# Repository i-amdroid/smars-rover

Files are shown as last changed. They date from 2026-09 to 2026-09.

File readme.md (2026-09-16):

SMARS ROVER
===========

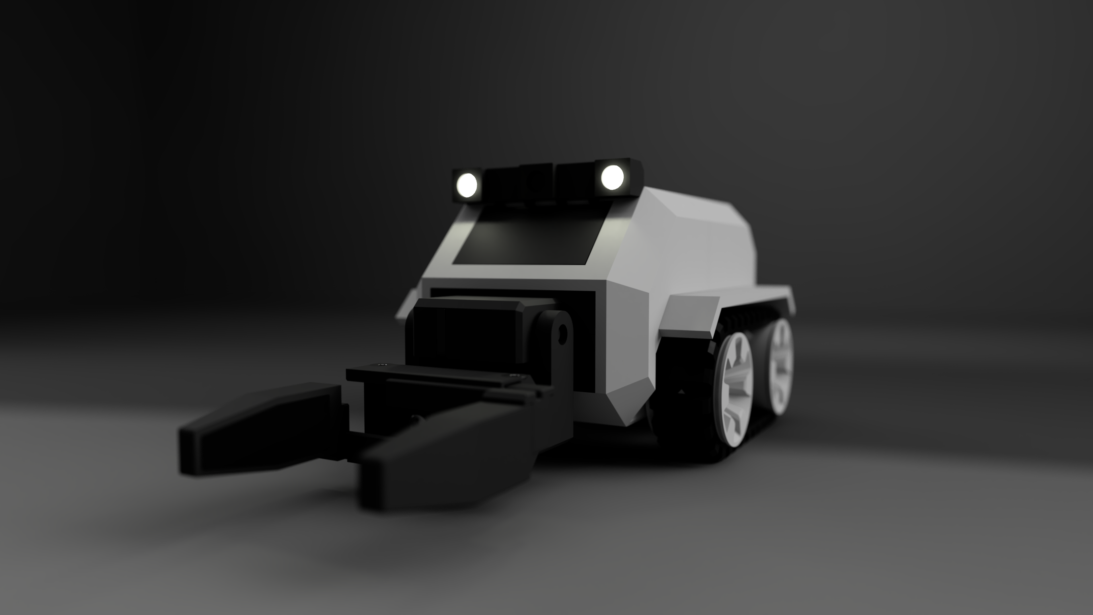
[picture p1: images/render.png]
SMARS ROVER


About the project
-----------------

SMARS ROVER is a modular robotic rover with a finger gripper, controlled remotely over a video stream and powered by an ESP32.
It is built on top of SMARS, an extendable modular robot with plenty of add-ons and a large community behind it.
The design was inspired by Toyota's JAXA lunar rover, the Mars rover from The Martian, and the original SMARS project.

Project features
----------------

* A complete, working project — free and open source
* Fully compatible with the SMARS robot project and most of its add-ons
* Rover body v3, carefully designed based on years of experience
* Improved chassis with support for a Li-ion battery and charging
* Flexible tracks and redesigned wheels
* Finger gripper that moves in two dimensions
* Custom PCB for a polished, professional build
* Remote powered by either a battery or a smartphone
* Remote control over ESP-NOW, with a range of up to 100 meters
* Video streaming over the USB webcam protocol, used to drive the rover and the gripper

Gallery
-------

| | | |
|---|---|---|
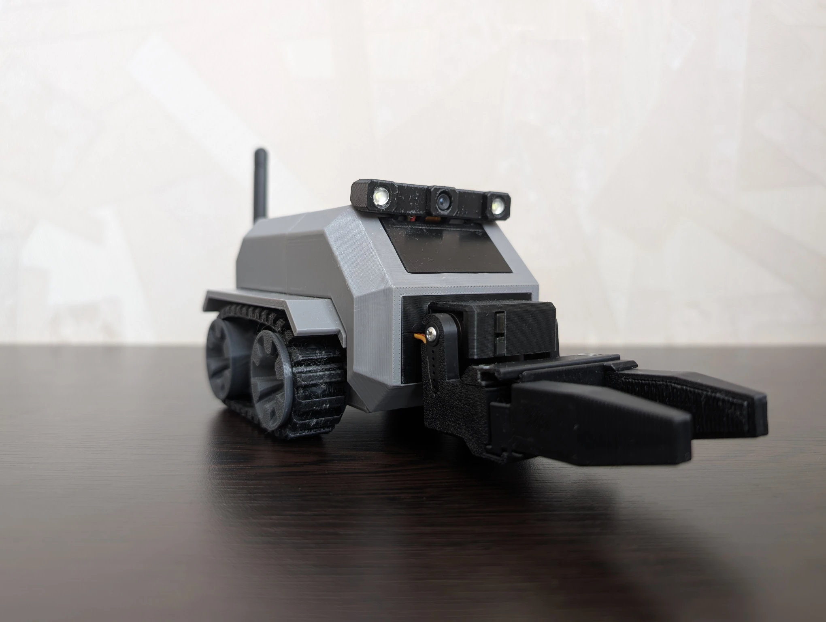
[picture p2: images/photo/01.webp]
Rover with the gripper open, front three-quarter view
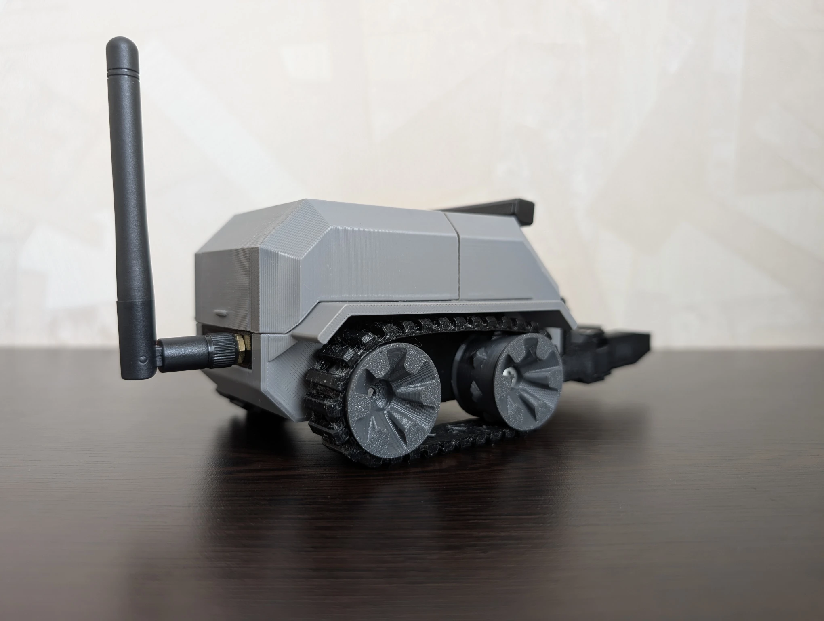
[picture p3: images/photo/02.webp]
Rover from the rear, with the external antenna
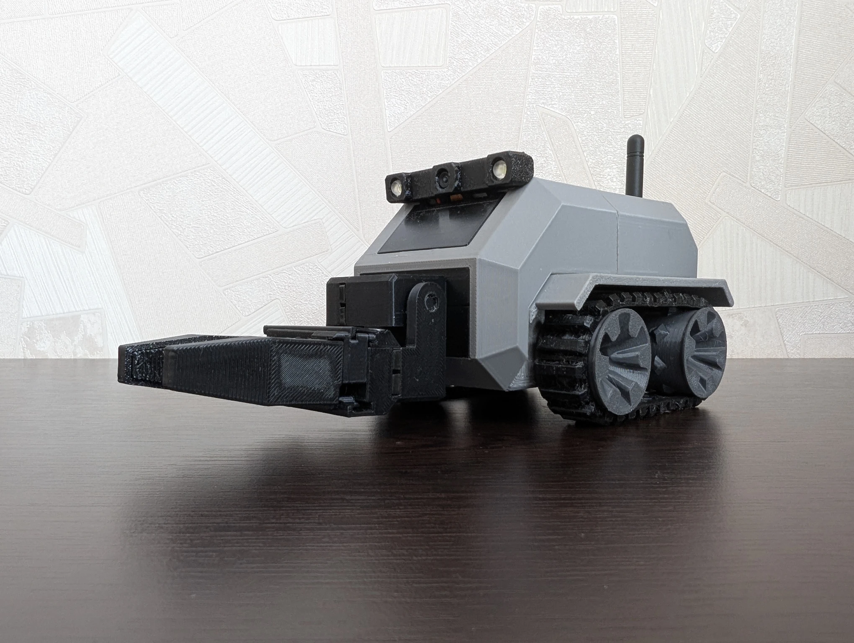
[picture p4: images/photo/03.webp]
Rover with the gripper reaching forward
|  |  |  |
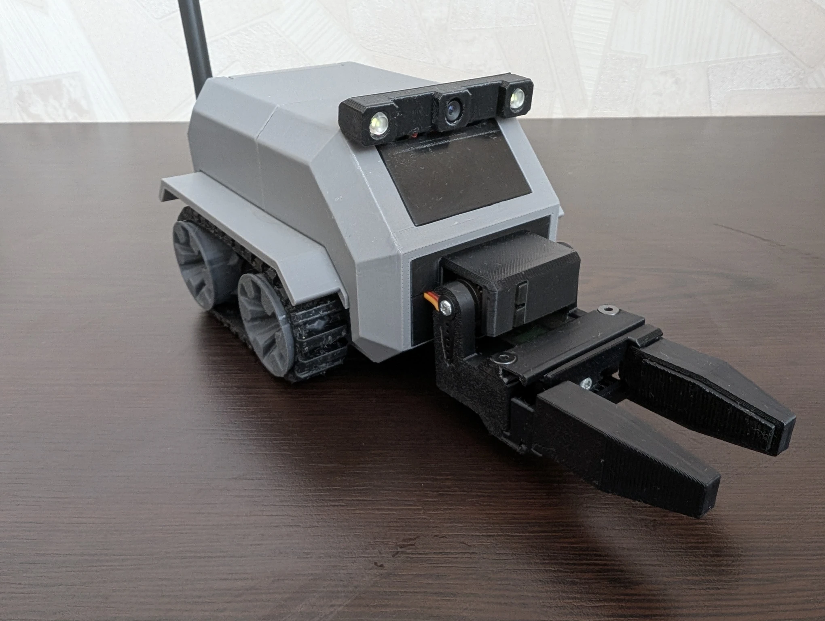
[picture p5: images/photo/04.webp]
Rover front three-quarter view, gripper open
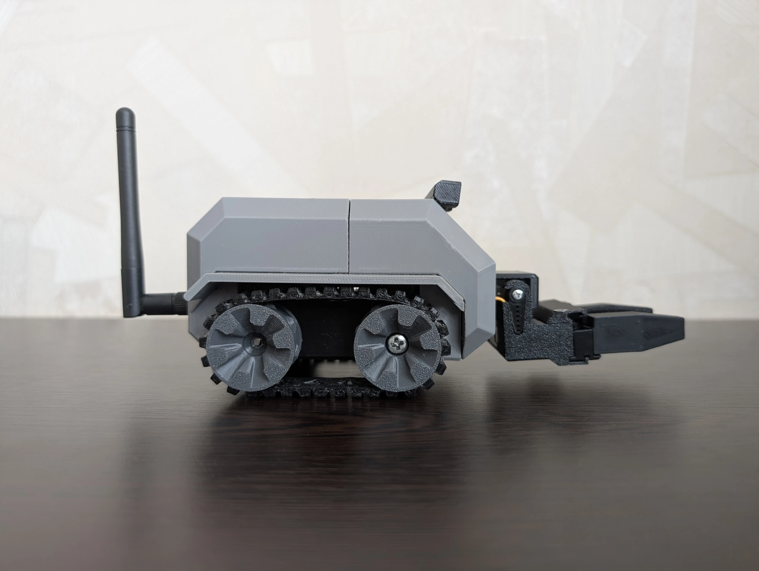
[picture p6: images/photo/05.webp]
Rover side profile
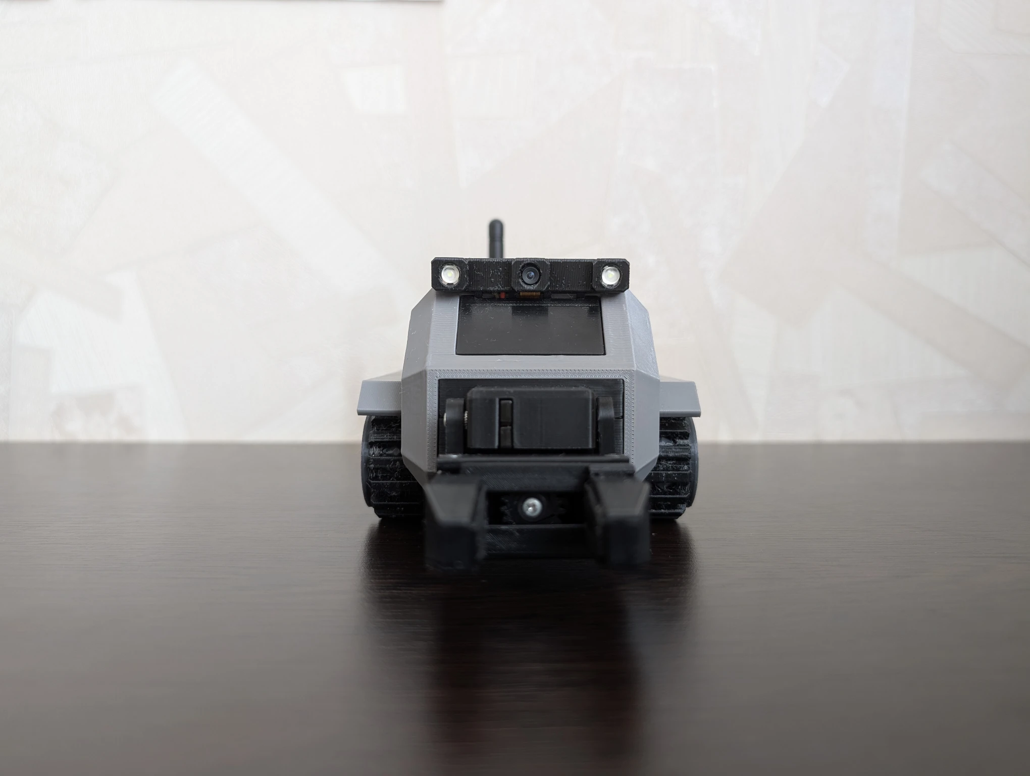
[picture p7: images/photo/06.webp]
Rover head-on, camera and lights
|  |  |  |
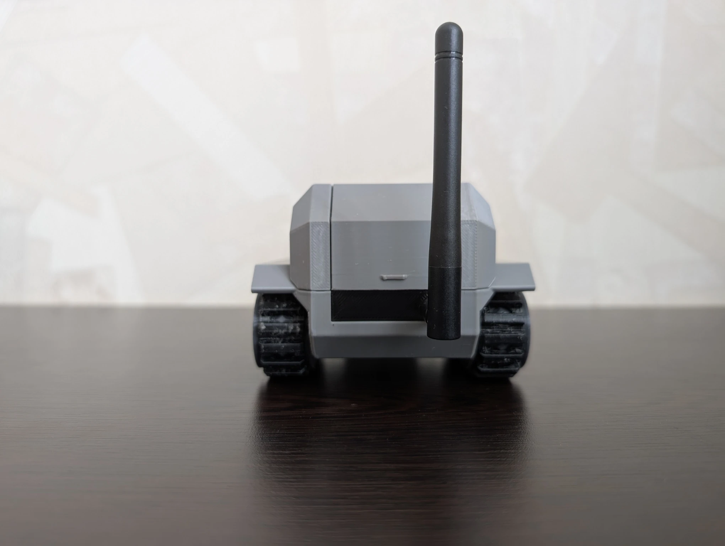
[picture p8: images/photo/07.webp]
Rover from behind, antenna raised
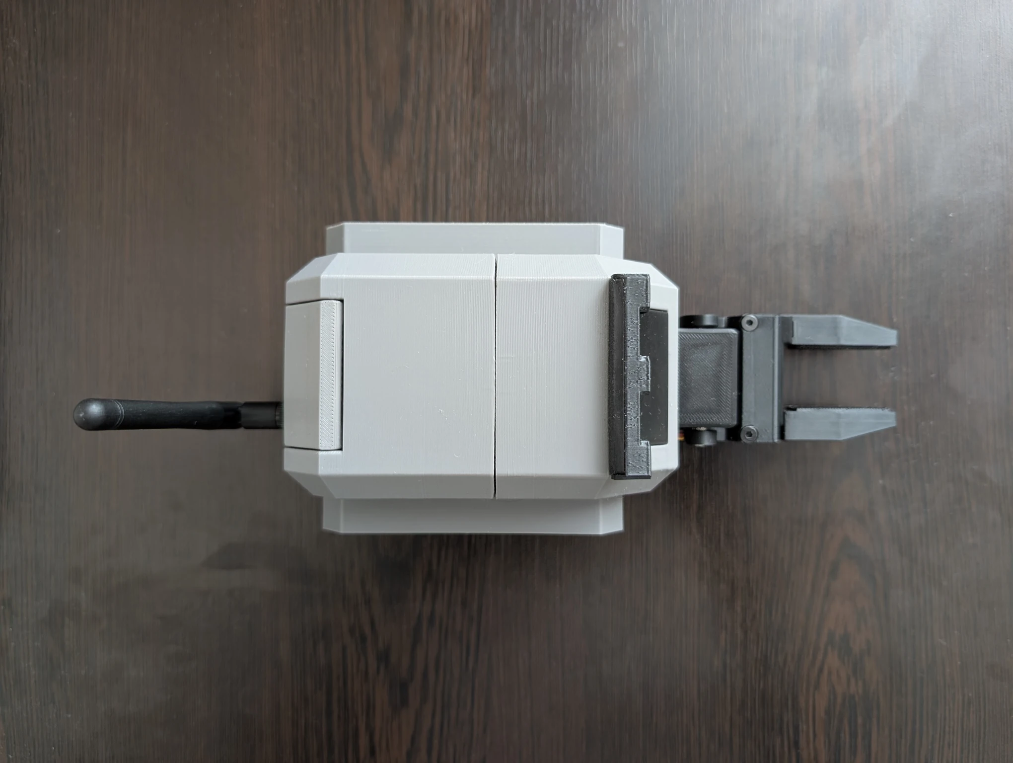
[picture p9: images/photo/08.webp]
Rover from above, gripper extended
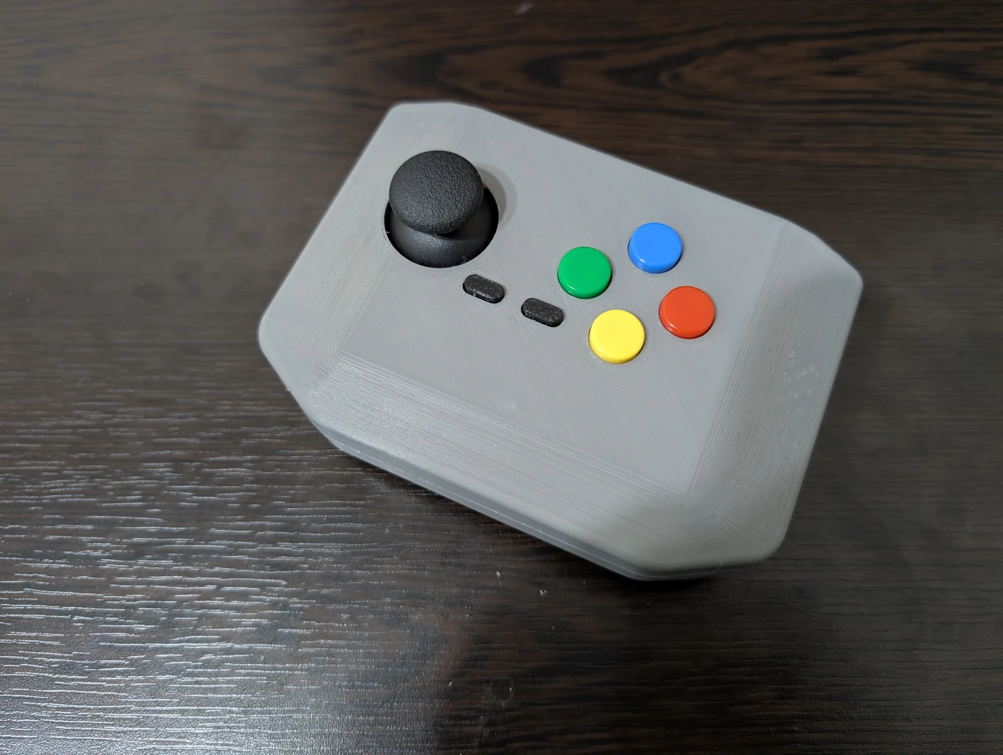
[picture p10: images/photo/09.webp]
Remote, three-quarter view
|  |  |  |
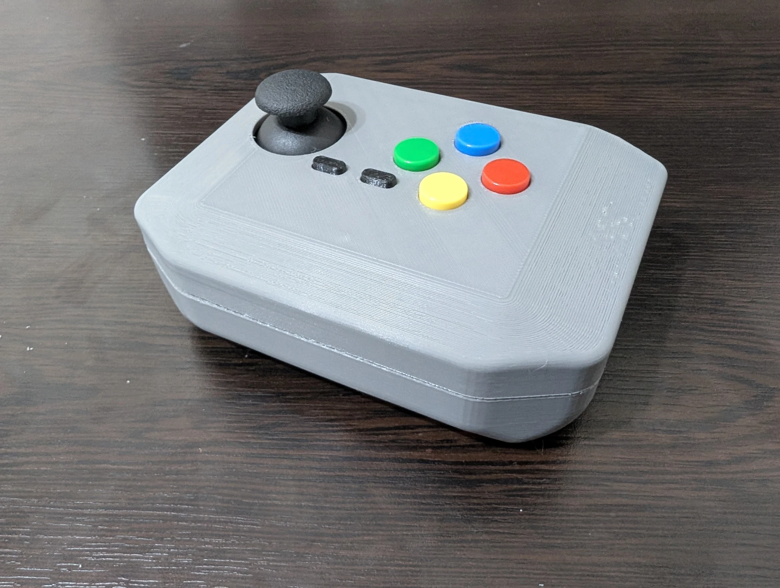
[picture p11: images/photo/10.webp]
Remote from the side
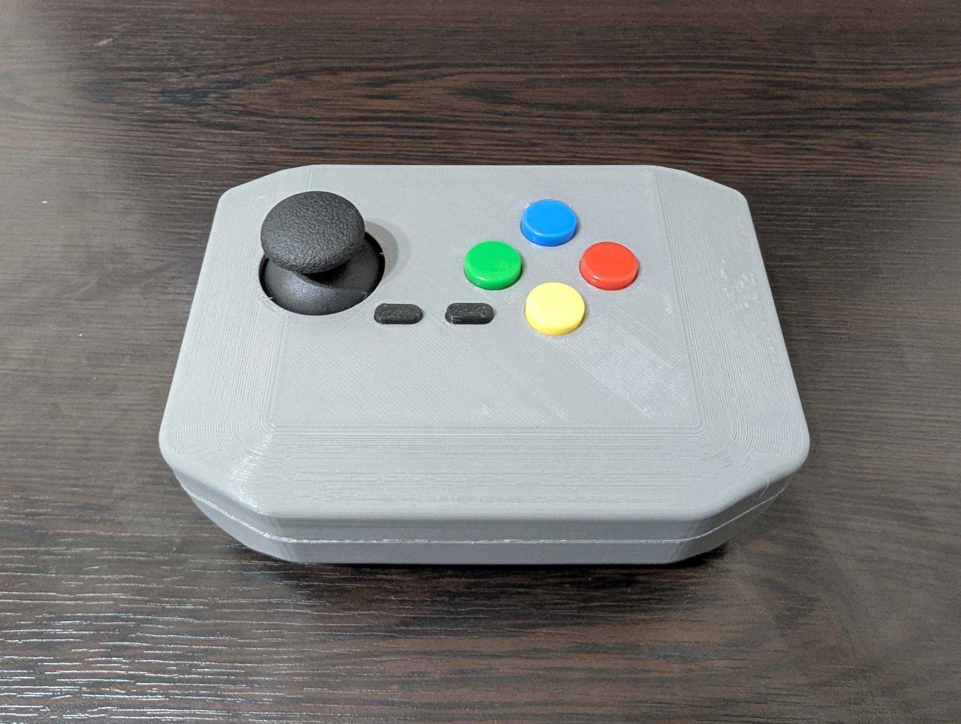
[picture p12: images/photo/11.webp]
Remote from above
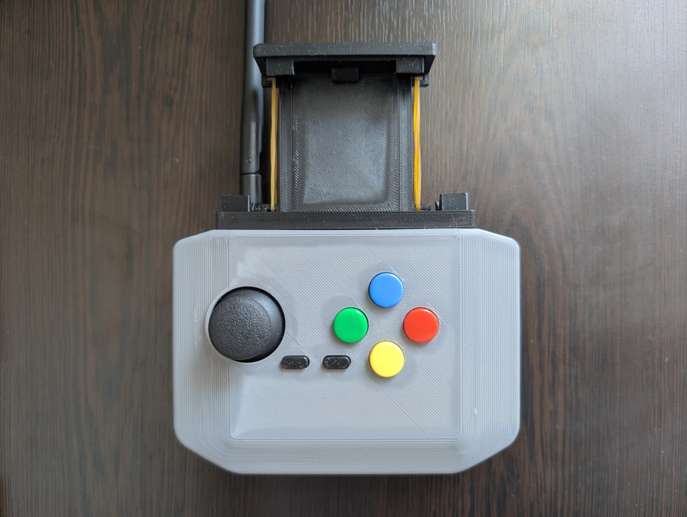
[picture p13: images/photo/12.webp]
Remote with the phone holder
|  |  |  |

Documentation
-------------

* [Parts list](/docs/parts-list.md)
* [3D printable parts](/docs/3d-print.md)
* [Assembly](/docs/assembly.md)
* [Software](/docs/software.md)

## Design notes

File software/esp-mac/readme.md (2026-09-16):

ESP MAC
=======

Prints the board's MAC address to the serial monitor, so you can pair the rover
and the remote. ESP-NOW addresses its peer by MAC, so each board has to be told
the address of the other one.

Usage
-----

```sh
pio run -e seeed_xiao_esp32s3 -t upload -t monitor
```

The address is printed every two seconds, so it can't be missed while the
monitor reconnects after a reset:

```
ESP32 Board MAC Address:  98:3D:AE:60:84:C0
```

Flash this to each of the two boards in turn and note which address belongs to
which. Then put the remote's address into `rover-esp` (`controllerMac`) and the
rover's address into `remote-webcam` (`robot_mac`), and flash the real firmware
over this sketch.

An alternative that needs no flashing at all is
[ESPConnect](https://thelastoutpostworkshop.github.io/ESPConnect/), which reads
the address over USB from the browser.

Two environments are configured: `seeed_xiao_esp32s3` (the boards used in this
project) and `esp32-s3-devkitc-1`.

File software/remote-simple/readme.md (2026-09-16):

Remote simple
=============

The remote before video was added: joystick and buttons sent to the rover over
ESP-NOW, nothing else. Useful if you build the rover without a camera, and a much
smaller sketch to read than `remote-webcam` if you want to see how the control
link works.

It sends the same `JoystickData` packet the rover expects, so it drives
`rover-esp` as-is (the camera simply stays off).

Joystick conditioning
---------------------

`remote-webcam` inherited this part unchanged:

* Each axis is the mean of 64 raw ADC reads. Oversampling removes noise spikes
  with no lag — deliberately no time-domain low-pass filter, which would make the
  output coast after release and leave the motors creeping.
* Readings are mapped to -1000..1000 against a calibrated min/centre/max, saved
  in NVS.
* A generous centre deadzone snaps the output to a hard zero at rest. It has to
  be wider than the noise swing near centre, otherwise the value crosses zero and
  the rover flips both tracks' direction.

Set `DEBUG_JOYSTICK` to `1` and open the serial monitor to print raw and mapped
values while tuning.

Usage
-----

Set `receiver_mac` to the rover's MAC address before flashing — see
[esp-mac](../esp-mac).

```sh
pio run -e seeed_xiao_esp32s3 -t upload -t monitor
```

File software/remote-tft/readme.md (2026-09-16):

Remote TFT
==========

A test sketch for the video stream. It receives 320x240 JPEG frames over ESP-NOW
from the rover (`rover-esp`) and draws them on a 2.4" 240x320 ILI9341 SPI TFT
(no touch) connected to a Seeed Studio XIAO ESP32-S3.

Use it to confirm that the rover is capturing and transmitting, without
involving a phone or the USB webcam path at all. It receives only — it sends no
joystick data, so it is a test rig rather than a working remote.

Built with [TFT_eSPI](https://github.com/Bodmer/TFT_eSPI) (display),
[TJpg_Decoder](https://github.com/Bodmer/TJpg_Decoder) (JPEG decode) and
[ESPNowCam](https://github.com/hpsaturn/ESPNowCam) (ESP-NOW transport).

- This board's MAC: `98:3D:AE:60:84:C0`
- Sender (rover-esp) MAC: `DC:DA:0C:57:59:C8`

Incoming JPEG frames are decoded and pushed to the screen in landscape
orientation from the ESPNowCam receive callback.

Wiring
------

The TFT module is powered and driven at 3.3V from the XIAO. The touch pins
(`T_*`) are unused on the no-touch module.

| TFT pin | Signal | XIAO pin | ESP32-S3 GPIO |
|---|---|---|---|
| VCC | 3.3V | 3V3 | — |
| GND | Ground | GND | — |
| CS | Chip select | D1 | GPIO2 |
| RESET | Reset | D3 | GPIO4 |
| DC (RS) | Data/command  | D2 | GPIO3 |
| SDI (MOSI)  | SPI data in | D10 | GPIO9 |
| SCK | SPI clock | D8 | GPIO7 |
| LED | Backlight | 3V3 | — |
| SDO (MISO)  | SPI data out  | D9 | GPIO8 |

Notes:
- `LED` (backlight) goes straight to 3.3V — the module has an onboard current
  limiting resistor. If your backlight is too bright you can drive it from a
  GPIO instead.
- `SDO`/MISO is optional for a write-only display, but it is wired here because
  TFT_eSPI expects the pin to be defined.
- If the image looks mirrored or rotated, change `tft.setRotation()` in
  `src/main.cpp` (0–3).

Pinout diagram
--------------

```
   XIAO ESP32-S3                      ILI9341 TFT (14-pin, no touch)
  +-------------+                     +-----------------------------+
  |        3V3  o---------+---------->o VCC                         |
  |        GND  o-------+ +---------->o LED  (backlight)            |
  |             |       +------------>o GND                         |
  |   D8 (G7)   o------------- SCK -->o SCK                         |
  |   D9 (G8)   o------------ MISO -->o SDO (MISO)                  |
  |   D10(G9)   o------------ MOSI -->o SDI (MOSI)                  |
  |   D2 (G3)   o------------- DC --->o DC                          |
  |   D3 (G4)   o------------ RST --->o RESET                       |
  |   D1 (G2)   o------------- CS --->o CS                          |
  +-------------+                     | T_* touch pins: unused      |
                                      +-----------------------------+
```

Usage
-----

```sh
pio run -t upload -t monitor
```

Power on the rover (`rover-esp`) too — once it starts streaming, frames appear
on the screen. The serial monitor prints `Receiver ready, waiting for
frames...`.

Both boards must be on the same ESP-NOW channel (both use the default channel,
so no configuration is needed).

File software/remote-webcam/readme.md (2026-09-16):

Remote webcam (controller)
==========================

The handheld controller. It reads a joystick + buttons and sends them to the
robot over ESP-NOW, receives the robot's 320x240 MJPEG video, and exposes that
video to an Android phone as a standard **USB UVC webcam**.

```
controller (this) --ESP-NOW joystick--> robot
robot --ESP-NOW MJPEG video--> controller --USB UVC--> Android
```

Received MJPEG is handed to the USB host as-is (no decoding). Plug the XIAO's
USB-C into an Android phone (OTG).

This merges the old `remote-simple` joystick controller into the video path.
Because the sketch is pure ESP-IDF (see below), the joystick is read with the
native `esp_adc` driver and sent with raw `esp_now`, not Arduino + ESPNowW.

Joystick / buttons / camera
---------------------------

- Sends a raw `JoystickData` struct (X/Y axes -1000..1000, 7 buttons, plus a
  `camera_on` flag) to the robot every ~50 ms via `esp_now_send`.
- The robot streams video only while `camera_on` is set. The **E button**
  toggles it (`CAMERA_TOGGLE_PIN` in `main.c`). When off, the controller's UVC
  `fb_get` returns nothing, so it idles instead of re-sending a frozen frame.
- Joystick calibration (center + extremes) is re-run by holding the **joystick
  button** for 5 s (centered phase, then sweep). Because the pot is ratiometric,
  its raw ADC values scale with the supply voltage, so a profile captured on one
  power source (e.g. USB/phone) misbehaves on another (e.g. a sagging battery).
  Two strategies, selected by `USE_NVS_CALIBRATION` in `main.c`:
  - **0 (default) — auto-adapt.** A compiled-in reference is rescaled at boot by
    `k = center_now / center_ref` to match the current supply (stick must be
    released at power-on; a wild `k` is ignored). Nothing is stored; a manual
    calibration lasts for the session only. Handles USB, full or half-drained
    battery without reflashing or per-source profiles.
  - **1 — NVS profile (old behaviour).** Absolute center/extremes are saved to
    and restored from NVS, with no supply compensation — recalibrate whenever the
    power source changes.
- Pins (Xiao ESP32-S3): X=GPIO1, Y=GPIO2; buttons A=3, B=4, C=5, D=6, E=9,
  F=8, joystick-press=7. (USB-OTG uses GPIO19/20, so no conflict.)

Build & flash (PlatformIO)
--------------------------

Normal PlatformIO workflow:

```sh
pio run                       # build
pio run -t upload             # flash
pio run -t upload -t monitor  # flash + serial (serial is on UART0, see below)
```

⚠️ Re-flashing: once the UVC firmware runs, the USB port is a webcam, so the
auto-reset used for flashing stops working. To re-flash, put the board in
download mode first (hold **BOOT**, tap **RESET**, release BOOT), then upload.

On the phone
------------

UVC is class-compliant, so **no driver** is needed. Install a **UVC viewer app**:
CameraFi, USB Camera, OTG View, etc. The recommended app is
https://gitlab.com/yaky/android-usb-cam-viewer. The phone must support USB-OTG.

How it's built (why not Arduino)
--------------------------------

This sketch uses `framework = espidf`, not `arduino`, even though the rest of
the project is Arduino. The USB UVC component (`usb_device_uvc`) needs ESP-IDF
5.x (= Arduino-ESP32 3.x), and on that core:

- ESPNowCam (0.2.x) doesn't compile — the esp_now callback signatures changed;
- building Arduino-as-a-component pulls in unrelated components that fail.

So the receive path talks to `esp_now` directly and decodes the rover's frames
with nanopb, reusing ESPNowCam's `frame.pb` wire format (byte-compatible with
the transmitter). The PlatformIO commands above are unchanged.

The `usb_device_uvc` component is vendored under `components/` with a one-line
patch (`PUBLIC` → `PRIVATE` on its `usb_descriptors.c`); without it PlatformIO's
build errors with "Two environments ... for the same target".

Notes
-----
- Needs the pioarduino platform (ships ESP-IDF 5.x); see `platformio.ini`.
- UVC advertises one format: MJPEG 320x240 @ up to 15 fps (`sdkconfig.defaults`),
  using bulk transfer mode (faster than isochronous on this chip).
- The frame rate you actually get depends heavily on the **Android UVC app** —
  some are much slower than others. If fps is low, try a different viewer before
  blaming the firmware.
- ESP32-S3 USB is full-speed; ample for QVGA MJPEG.
- Serial logs go to UART0 (not USB) since UVC owns the USB port.
- A pure ESP-IDF / `idf.py` copy of the original video-only receiver is kept in
  `../test-webcam-idf` as a reference/fallback.

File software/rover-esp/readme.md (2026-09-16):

Rover ESP
=========

The robot. A Seeed Studio XIAO ESP32-S3 Sense that drives two N20 motors (via a
DRV8833), moves a 2-servo manipulator, and streams its camera over ESP-NOW to
the controller (`remote-webcam`). It receives joystick/button data from the
controller over ESP-NOW.

```
controller --ESP-NOW joystick--> rover (this)
rover --ESP-NOW MJPEG video--> controller
```

Video uses [ESPNowCam](https://github.com/hpsaturn/ESPNowCam); joystick is
received with a raw `esp_now` callback; servos use ESP32Servo; the DRV8833
is driven directly with LEDC PWM (no library).

Wiring (Xiao ESP32-S3)
----------------------

| Function | XIAO | GPIO |
|---|---|---|
| Servo 1 (shoulder) PWM | D0 | 1 |
| Servo 2 (gripper) PWM | D1 | 2 |
| DRV8833 IN1 (motor 1) | D6 | 43 |
| DRV8833 IN2 (motor 1) | D5 | 6 |
| DRV8833 IN3 (motor 2) | D4 | 5 |
| DRV8833 IN4 (motor 2) | D3 | 4 |
| White LEDs (S8050 base) | D7 | 44 |

Controls
--------

- **Joystick** → tank drive (two motors, mixed).
- **A / C** → servo 1 (shoulder) up / down. **B / D** → servo 2 (gripper)
  close / open. Hold to move, release to hold position.
- **E** (on the controller) → camera on/off. **Default off.** When off the
  camera is de-initialised — no capture, encode or radio traffic.
- **F** (on the controller) → white LEDs on/off. **Default off.**
- Failsafe: if no control packet arrives for 500 ms the motors stop.

Usage
-----

```sh
pio run -t upload -t monitor
```

Notes
-----

- DRV8833 needs no library: speed = PWM duty on an input, direction = which of
  the two inputs gets the PWM. Motors on LEDC channels 4-7; servos (ESP32Servo)
  use LEDC timers 0-1.
- Tunables in `src/main.cpp`:
  - **Per-build motor wiring** — `leftMotor` / `rightMotor` (`MotorConfig`): which
    DRV8833 channel pair drives each track and a `reversed` flag. Adapt a new
    assembly by editing just these two lines (this build has the connectors
    swapped and the left motor reversed).
  - Speed: `MIN_SPEED` (kick-start floor) / `MAX_SPEED`, `MOTOR_CORRECTION`.
  - Servo: angle limits (`S1_*`, `S2_*`) and pulse range `SERVO_MIN_US` /
    `SERVO_MAX_US` (calibrated to 600-2400 µs so 0° doesn't jam past the stop).
- Known quirk: `DRV_IN1` sits on D6 (GPIO43 = UART TX), which idles HIGH during
  boot, so the right track spins forward for ~1-2 s at power-on until the
  firmware takes the pin.
- Camera default off, so the rover boots cool and quiet; it spins the camera up
  only when the controller asks.

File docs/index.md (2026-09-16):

SMARS ROVER documentation
=========================

* [Parts list](parts-list.md)
* [3D printable parts](3d-print.md)
* [Assembly](assembly.md)
* [Software](software.md)

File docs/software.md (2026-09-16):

Software
========

All firmware for the project lives in the [`software/`](./../software) folder. Every sketch is a self-contained [PlatformIO](https://platformio.org/) project — a folder with its own `platformio.ini`, which is what you open in the editor.

Two of the sketches are the ones you actually flash to build a working rover:

* **`rover-esp`** — the rover.
* **`remote-webcam`** — the remote.

Everything else is either a small utility or an earlier variant kept for reference.

Sketches
--------

| Sketch | Board | Framework | What it is |
|---|---|---|---|
| [`rover-esp`](./../software/rover-esp) | XIAO ESP32-S3 Sense | Arduino | **Rover firmware.** Drives the two motors, moves the gripper servos, switches the lights, and streams the camera to the remote over ESP-NOW. |
| [`remote-webcam`](./../software/remote-webcam) | XIAO ESP32-S3 | ESP-IDF | **Remote firmware.** Reads the joystick and buttons, sends them to the rover, receives the video, and presents it to a phone as a USB webcam. |
| [`esp-mac`](./../software/esp-mac) | any ESP32 | Arduino | Utility. Prints the board's MAC address to the serial monitor. You need this once, during setup. |
| [`remote-tft`](./../software/remote-tft) | XIAO ESP32-S3 | Arduino | Test sketch for the video stream. Receives the rover's video and shows it on a 2.4" ILI9341 SPI screen, with no phone involved. |
| [`remote-simple`](./../software/remote-simple) | XIAO ESP32-S3 | Arduino | The earlier remote: joystick and buttons over ESP-NOW, no video. Useful if you build the rover without a camera. |

Setting up PlatformIO
---------------------

PlatformIO handles the toolchains, board definitions and libraries for you — there is nothing to install by hand.

1. Install [Visual Studio Code](https://code.visualstudio.com/) and the **PlatformIO IDE** extension. (If you prefer the command line, [PlatformIO Core](https://docs.platformio.org/en/latest/core/quickstart.html) alone is enough.)
2. Open the folder of a single sketch — for example `software/rover-esp`, the folder that contains `platformio.ini`. Do not open `software/` itself.
3. The first build downloads the platform, toolchain and libraries. This takes a few minutes; later builds are fast.

The commands below are run from the sketch folder.

```sh
pio run                       # build
pio run -t upload             # build and flash
pio run -t upload -t monitor  # build, flash, and open the serial monitor
pio device monitor -b 115200  # serial monitor only
pio check                     # static analysis
pio pkg update                # update platforms and libraries
```

If a sketch defines several boards (`[env:...]` sections in `platformio.ini`), pick one with `-e`:

```sh
pio run -e seeed_xiao_esp32s3 -t upload
```

Getting the rover running
-------------------------

The rover and the remote talk to each other over ESP-NOW, which addresses peers by MAC address. Each board therefore has to be told the MAC address of the other one. This is the only change you *have* to make before flashing.

### 1. Read both MAC addresses

Flash `esp-mac` to each of the two ESP32 boards in turn and open the serial monitor:

```sh
pio run -e seeed_xiao_esp32s3 -t upload -t monitor
```

It prints the address every two seconds:

```
ESP32 Board MAC Address:  98:3D:AE:60:84:C0
```

Write down which address belongs to the rover board and which to the remote board. Alternatively, use [ESPConnect](https://thelastoutpostworkshop.github.io/ESPConnect/), which reads the address over USB without flashing anything.

### 2. Put each address into the other sketch

**The rover** needs the remote's address. In `software/rover-esp/src/main.cpp`:

```cpp
// Controller MAC (peer) — video is sent here. Set to your controller's MAC.
static uint8_t controllerMac[6] = {0x98, 0x3D, 0xAE, 0x61, 0x72, 0x3C};
```

**The remote** needs the rover's address. In `software/remote-webcam/src/main.c`:

```cpp
// Rover MAC (peer) — joystick frames are sent here. Set to your rover's MAC.
static uint8_t robot_mac[6] = {0x98, 0x3D, 0xAE, 0x60, 0x84, 0xC0};
```

The values shipped in the repository are the author's own boards — replace both.

### 3. Flash the two sketches

Flash `rover-esp` to the rover board and `remote-webcam` to the remote board. Both boards use the default ESP-NOW channel, so there is nothing else to pair or configure.

> **Warning:** never power an ESP32 board without an antenna connected, over USB or from the battery. Transmitting without an antenna can damage the board. See the [Assembly](assembly.md) guide.

Rover firmware (`rover-esp`)
----------------------------

A single Arduino sketch that does four things at once: tank drive, two servos, the white LEDs, and the camera stream.

### Controls

| Input | Action |
|---|---|
| Joystick | Tank drive. Pushed forward or back, the rover drives and steers in an arc — the inner track slows but never reverses. With the stick centred vertically, left and right pivot the rover in place. |
| **A** / **C** | Servo 1 (shoulder) up / down. |
| **B** / **D** | Servo 2 (gripper) close / open. |
| **E** | Camera on/off. **Off by default** — when off, the camera is powered down entirely, so the rover runs cooler and quieter. |
| **F** | White LEDs on/off. **Off by default.** |

The servos are velocity-driven: hold a button and the servo steps toward its limit at about 66°/s; release it and the servo holds its position.

If no control packet arrives for 500 ms — the remote is switched off, or out of range — the motors stop and the servos stop moving.

### Wiring

| Function | XIAO pin | GPIO |
|---|---|---|
| Servo 1 (shoulder) PWM | D0 | 1 |
| Servo 2 (gripper) PWM | D1 | 2 |
| DRV8833 IN1 (motor 1) | D6 | 43 |
| DRV8833 IN2 (motor 1) | D5 | 6 |
| DRV8833 IN3 (motor 2) | D4 | 5 |
| DRV8833 IN4 (motor 2) | D3 | 4 |
| White LEDs (S8050 base) | D7 | 44 |

### What you may need to change

Everything below is a constant near the top of `src/main.cpp`.

**If a track runs backwards, or the rover turns the wrong way**, edit the two motor configuration lines. Which DRV8833 channel pair drives which track, and whether that motor is reversed, is the one thing that genuinely differs between builds:

```cpp
static MotorConfig leftMotor  = { M2A_CH, M2B_CH, true  };  // left  track on M2
static MotorConfig rightMotor = { M1A_CH, M1B_CH, false };  // right track on M1
```

**Speed and handling:**

| Constant | Meaning |
|---|---|
| `MIN_SPEED` / `MAX_SPEED` | PWM duty range, 0–255. `MIN_SPEED` is the point where the N20 motors actually start turning instead of buzzing. |
| `MOTOR_CORRECTION` | Trim, if the rover drifts to one side. `1.0` is no trim; below 1 trims the right track, above 1 trims the left. |
| `STEER_GAIN` | How sharply the rover turns while driving — how much the inner track slows at full steering. |
| `PIVOT_MIN_SPEED` | Duty floor for pivoting in place. Turning on the spot scrubs both tracks sideways and needs far more torque than driving, so this is much higher than `MIN_SPEED`. |
| `DEADZONE` | Joystick travel around the centre that counts as "no input". |

**Gripper travel:** `S1_MIN` / `S1_MAX` / `S1_INIT` for the shoulder and `S2_*` for the fingers. Swap the min and max to reverse a servo's direction. `SERVO_MIN_US` / `SERVO_MAX_US` is the pulse range, calibrated to 520–2480 µs for the MG90S — the stock 500–2500 µs drives the servo past its mechanical stop, where it can jam. Adjust if your servos differ.

**Camera:** `CAM_HMIRROR` and `CAM_VFLIP` fix the image orientation if the camera is mounted rotated or mirrored. `FRAME_INTERVAL_MS` paces the stream.

### Notes

* The camera streams QVGA (320×240) MJPEG. The CPU runs at 160 MHz and the radio at reduced transmit power, both to keep the board cool inside the printed body.
* `DRV_IN1` sits on D6 (GPIO43), which is the UART TX pin and idles high during boot. The right track spins forward for a second or two at power-on, until the firmware takes the pin over.
* The DRV8833 needs no library: speed is the PWM duty on one input, direction is which of the two inputs gets it.

Remote firmware (`remote-webcam`)
---------------------------------

The remote reads the joystick and buttons, sends them to the rover roughly every 50 ms, receives the rover's video, and exposes that video to an Android phone as a **standard USB webcam** (UVC).

```
remote --ESP-NOW joystick--> rover
rover --ESP-NOW MJPEG video--> remote --USB UVC--> phone
```

### Using it with a phone

Plug the remote's USB-C port into the phone with an OTG cable. UVC is class-compliant, so no driver is needed — you just need a **UVC viewer app**. [android-usb-cam-viewer](https://gitlab.com/yaky/android-usb-cam-viewer) is the recommended one; CameraFi, USB Camera and OTG View also work. The phone must support USB-OTG.

The video is MJPEG 320×240 at up to 15 fps. The frame rate you actually get depends heavily on the viewer app — if it feels slow, try a different one before blaming the firmware.

### Joystick calibration

The joystick is a plain potentiometer, so its readings scale with the supply voltage: a profile captured on USB power misbehaves on a half-drained battery. The firmware handles this automatically — at boot it rescales a built-in reference to the current supply. Nothing is stored, and nothing needs configuring.

To recalibrate by hand, hold the **joystick button** for 5 seconds: first with the stick released (this captures the centre), then sweep it to all extremes. A manual calibration lasts for the current session only.

If you would rather store an absolute profile in flash, set `USE_NVS_CALIBRATION` to `1` in `src/main.c`. That profile does not compensate for supply voltage, so you have to recalibrate whenever the power source changes.

### Wiring

Joystick X on GPIO1, Y on GPIO2. Buttons: **A** = 3, **B** = 4, **C** = 5, **D** = 6, **E** = 9, **F** = 8, joystick press = 7. USB-OTG uses GPIO19/20, so there is no conflict.

### Re-flashing

⚠️ Once the firmware is running, the USB port *is* a webcam, so the automatic reset used for flashing no longer works. To re-flash, put the board into download mode first: **hold BOOT, tap RESET, release BOOT**, then upload.

Serial logs go to UART0 rather than USB, for the same reason.

### What you may need to change

| Where | Constant | Meaning |
|---|---|---|
| `src/main.c` | `robot_mac` | The rover's MAC address. |
| `src/main.c` | `CAMERA_TOGGLE_PIN` | Which button toggles the camera (**E** by default). |
| `src/main.c` | `OUTPUT_DEADZONE` | Joystick centre deadzone. Must be wider than the noise at rest, otherwise the output crosses zero and the rover twitches. |
| `src/main.c` | `USE_NVS_CALIBRATION` | Calibration strategy, see above. |
| `sdkconfig.defaults` | `CONFIG_UVC_CAM1_FRAMERATE` | Advertised frame rate. |
| `sdkconfig.defaults` | `CONFIG_TUSB_PRODUCT` | The name the phone shows for the webcam. |

### Why this one is not an Arduino sketch

`remote-webcam` uses `framework = espidf`, unlike every other sketch in the project. The USB UVC stack needs ESP-IDF 5.x, and on that core the ESPNowCam library does not build. So this sketch talks to `esp_now` directly and decodes the rover's frames with nanopb, reusing ESPNowCam's wire format so the two ends stay compatible.

Two consequences, both already handled in `platformio.ini`:

* It needs the **pioarduino** platform, which ships ESP-IDF 5.x. PlatformIO downloads it on the first build.
* That platform registers itself as `espressif32` and would shadow the stock one, so this project keeps its packages in a separate core directory (`~/.platformio-pioarduino`). Every other sketch carries on using the normal global installation.

Other sketches
--------------

### `esp-mac`

Prints the board's MAC address to the serial monitor, twice a second. Flash it, read the address, flash something else. See [Getting the rover running](#getting-the-rover-running).

### `remote-tft`

A test sketch for the video stream. It receives the rover's frames and draws them on a 2.4" 240×320 ILI9341 SPI display wired to a XIAO ESP32-S3, so you can confirm the rover is capturing and transmitting without involving a phone or the USB webcam path at all. It receives only — it sends no joystick data.

The display is configured through build flags in `platformio.ini`, so the setup travels with the project and you do not need to edit the TFT_eSPI library. Wiring and a pinout diagram are in the [sketch's readme](./../software/remote-tft/readme.md).

### `remote-simple`

The remote before video was added: joystick and buttons over ESP-NOW, nothing else. It carries the joystick conditioning that `remote-webcam` later inherited — oversampling, calibration, a centre deadzone. Worth using if you build the rover without a camera, or as a much smaller sketch to read when working out how the control link fits together.

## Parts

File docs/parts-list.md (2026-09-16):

Parts list
==========

| Image | Part name | Used in / Comments | Links | Quantity |
|---|---|---|---|---|
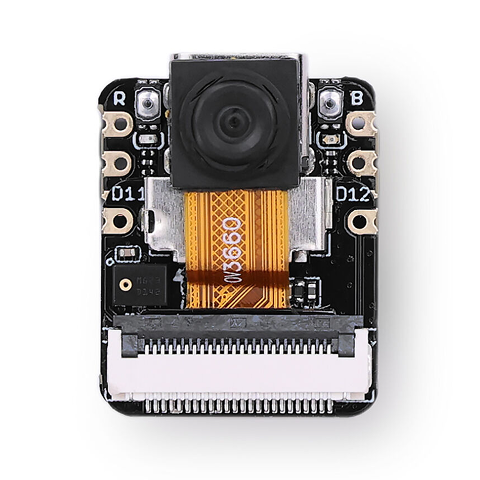
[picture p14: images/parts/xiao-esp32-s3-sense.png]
|  | Seeed Studio XIAO ESP32-S3 Sense | Rover, the camera sensor board is required for video streaming | [seeedstudio.com](https://www.seeedstudio.com/XIAO-ESP32S3-Sense-p-5639.html) | 1 |
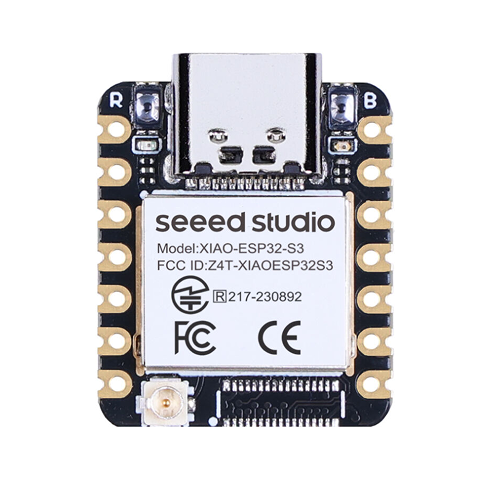
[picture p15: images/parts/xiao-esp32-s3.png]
|  | Seeed Studio XIAO ESP32-S3 | Remote | [seeedstudio.com](https://www.seeedstudio.com/XIAO-ESP32S3-p-5627.html) | 1 |
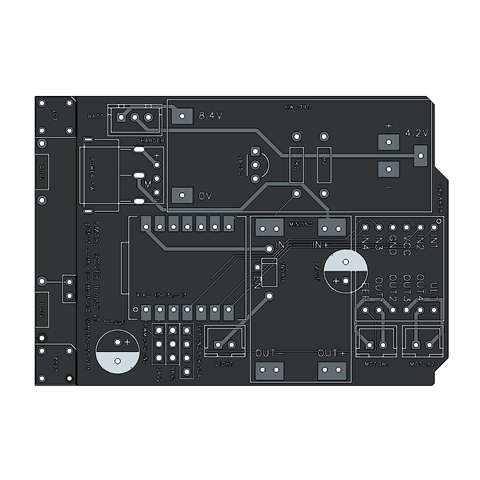
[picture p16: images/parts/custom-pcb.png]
|  | Custom PCB | Rover, optional, alternatives allowed* | [jlcpcb.com](https://jlcpcb.com/) | 1 |
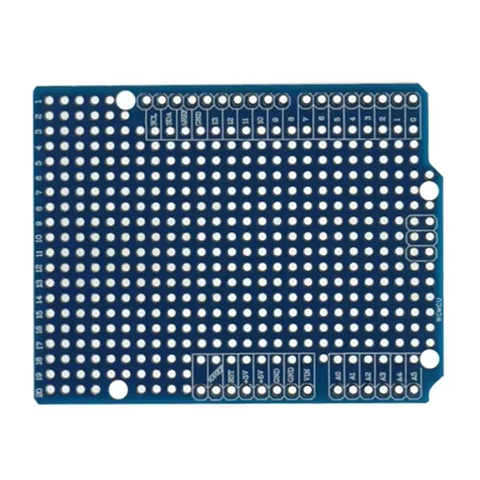
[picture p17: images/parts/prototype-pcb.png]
|  | Prototype PCB Uno R3 | Rover, an alternative to custom PCB | [aliexpress.com](https://aliexpress.com/item/1005009263224615.html) | 1 |
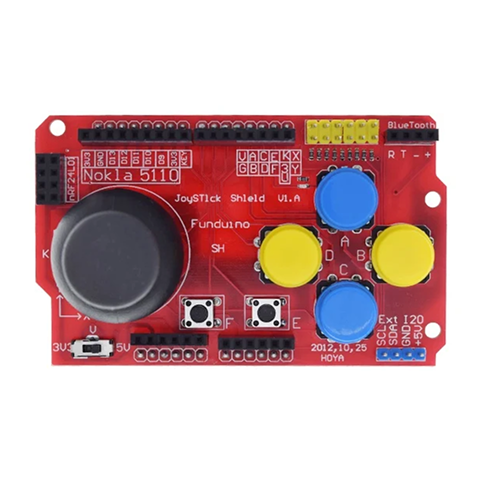
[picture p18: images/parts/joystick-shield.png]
|  | Joystick shield | Remote | [aliexpress.com](https://aliexpress.com/item/1005005876862901.html) | 1 |
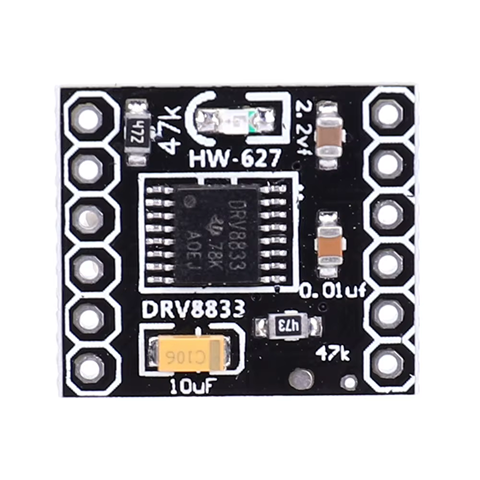
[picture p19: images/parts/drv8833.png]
|  | DRV8833 dual DC motor driver | Rover | [aliexpress.com](https://aliexpress.com/item/1005008581957341.html) | 1 |
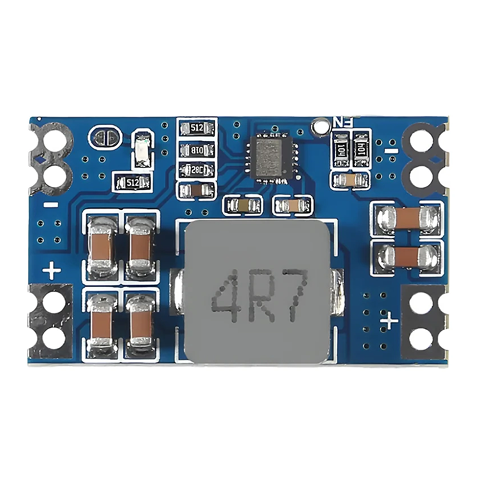
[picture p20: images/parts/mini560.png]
|  | Mini560 step-down DC-DC converter (5A) | Rover, alternatives allowed* | [aliexpress.com](https://aliexpress.com/item/1005008374043122.html) | 1 |
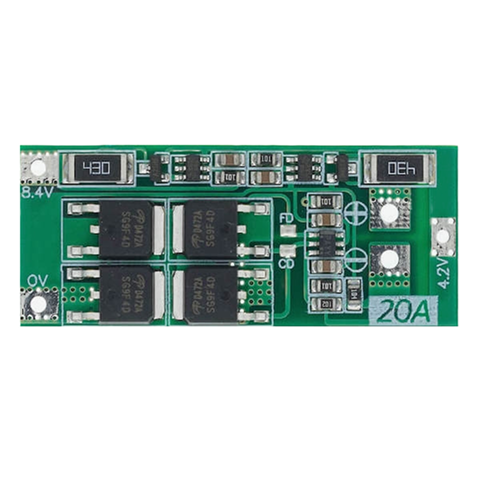
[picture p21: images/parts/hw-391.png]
|  | HW-391 2S balance BMS | Rover, alternatives allowed* | [aliexpress.com](https://aliexpress.com/item/1005006332151598.html) | 1 |
|  | IP2326 2S/3S charger | Rover, optional, alternatives allowed* | [aliexpress.com](https://aliexpress.com/item/1005009467084475.html) | 1 |
|  | TP4056 mini 1S charger (Type-C) | Remote, alternatives allowed* | [aliexpress.com](https://aliexpress.com/item/1005004851048196.html) | 1 |
|  | N20 6V DC gear motor (200 RPM) | Rover | [aliexpress.com](https://aliexpress.com/item/1005006728064342.html) | 2 |
|  | MG90S micro servo (180°) | Rover, required for gripper. Note: servos come in different shapes, and not all of them fit. | [aliexpress.com](https://aliexpress.com/item/33044819391.html) | 2 |
|  | Wi-Fi antenna 2.4GHz, IPEX | Rover, Remote, recommended for video streaming | [aliexpress.com](https://aliexpress.com/item/1005006297440958.html) | 2 |
|  | OV3660 camera, 75mm (120°) | Rover, required for video streaming, alternatives allowed* | [aliexpress.com](https://aliexpress.com/item/1005006846294692.html) | 1 |
|  | 14500 Li-ion battery 800mAh | Rover, Remote, alternatives allowed* | [aliexpress.com](https://aliexpress.com/item/1005001984637431.html) [aliexpress.com](https://aliexpress.com/item/1005009607272016.html) | 3 |
|  | 1S AA battery holder | Remote | [aliexpress.com](https://aliexpress.com/item/1005008680112094.html) | 1 |
|  | SS12D11 toggle switch | Rover, Remote, alternatives allowed* | [aliexpress.com](https://aliexpress.com/item/1005002546022458.html) | 2 |
|  | Resistor 100Ω | Rover, required for light |  | 2 |
|  | Resistor 1000Ω | Rover, required for light |  | 1 |
|  | Resistor 10KΩ | Rover, required for light |  | 1 |
|  | Capacitor 220µF | Rover |  | 1 |
|  | Capacitor 100µF | Rover, optional |  | 1 |
|  | Capacitor 10nF | Rover, optional | | 2 |
|  | Schottky diode 1N5819 | Rover, alternatives allowed* |  | 1 |
|  | NPN transistor S8050 | Rover, required for light, alternatives allowed* |  | 1 |
|  | Piranha LED 5mm white | Rover, required for light, alternatives allowed* | [aliexpress.com](https://aliexpress.com/item/1005002270502759.html) | 2 |
|  | OTG data cable | Rover, Remote, required for video streaming | [aliexpress.com](https://aliexpress.com/item/1005012334389121.html) | 1 |
|  | Aluminum heatsink 10x10x10mm | Rover, recommended for video streaming | [seeedstudio.com](https://www.seeedstudio.com/Aluminum-Heat-Sink-For-XIAO-2pcs-p-5972.html) [aliexpress.com](https://aliexpress.com/item/4000299061064.html) | 2 |
|  | JST XH2.54 connectors (2P, 3P) | Rover, optional. Note: requires an SN-2549 crimper. | [aliexpress.com](https://aliexpress.com/item/1005010378625298.html) |  |
|  | 2.54mm male pin header | Rover, optional | [aliexpress.com](https://aliexpress.com/item/4000694199194.html) |  |
|  | 2.54mm female header | Rover, optional | [aliexpress.com](https://aliexpress.com/item/4000523047541.html) |  |
|  | Wires with Dupont connectors (female-female) | Remote |  |  |
|  | Wires without connector | Rover, Remote |  |  |
|  | Nickel strip | Rover | [aliexpress.com](https://aliexpress.com/item/32905320656.html) |  |
|  | M4x30 screw | Rover |  | 2 |
|  | M4 self-locking nut | Rover |  | 2 |
|  | M3x20 flat head screw | Rover, required for gripper |  | 2 |
|  | M3x16 flat head screw | Rover, required for gripper |  | 2 |
|  | M3x12 set screw | Rover, optional |  | 2 |
|  | M3 square nut | Rover, optional |  | 2 |
|  | M3x5 screw with pad (screw for computer case) | Rover, alternatives allowed* |  | 11 |
|  | M3x5 screw | Remote, can also be used as an alternative to the M3x5 screw with pad |  | 2 |
|  | M3x5 flat head screw | Remote |  | 1 |
|  | M3 insert nut | Rover, Remote, optional* |  | 13 |

<div>* — these parts may require adjustments to the 3D-printed models.</div>

Links are not referrals and are provided for reference. Feel free to buy components wherever you like.

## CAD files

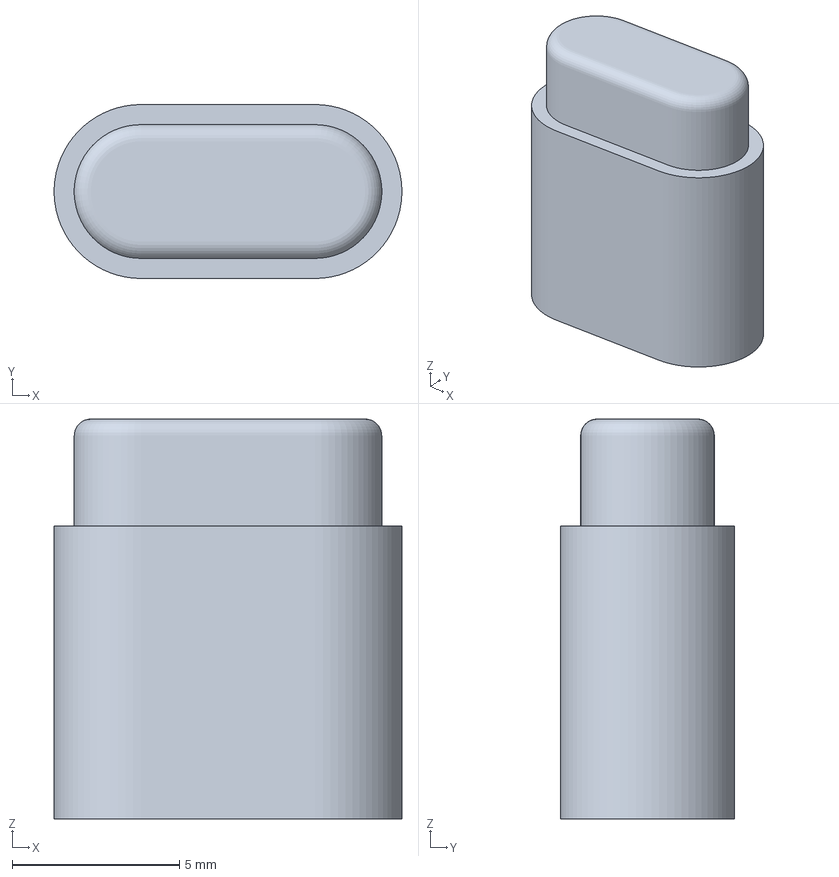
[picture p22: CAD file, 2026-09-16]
3d-print/remote/parts/small-button.3mf
10.4 x 5.20 x 12.0 mm

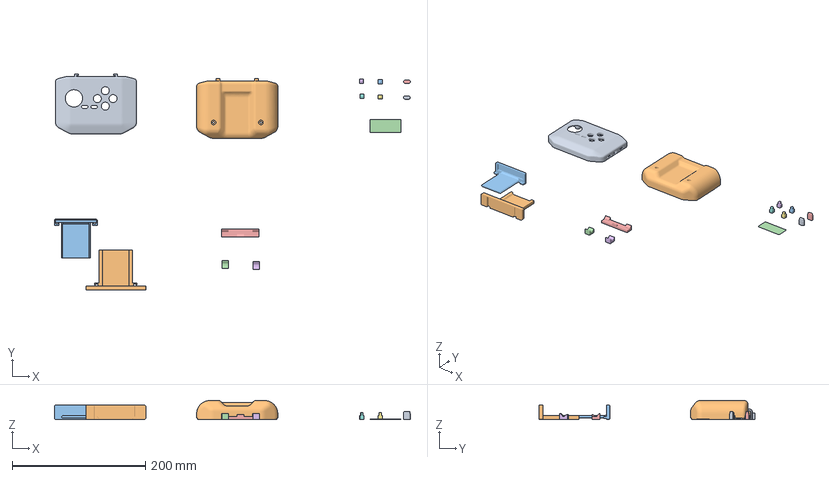
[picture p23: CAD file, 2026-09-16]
3d-print/remote/remote.3mf
534.7 x 324.2 x 28.5 mm
top
bottom
button-connector x 4
antenna-pad
small-button x 2
holder-base
holder-cap
holder-base-rubber-1 x 2
holder-cap-rubber

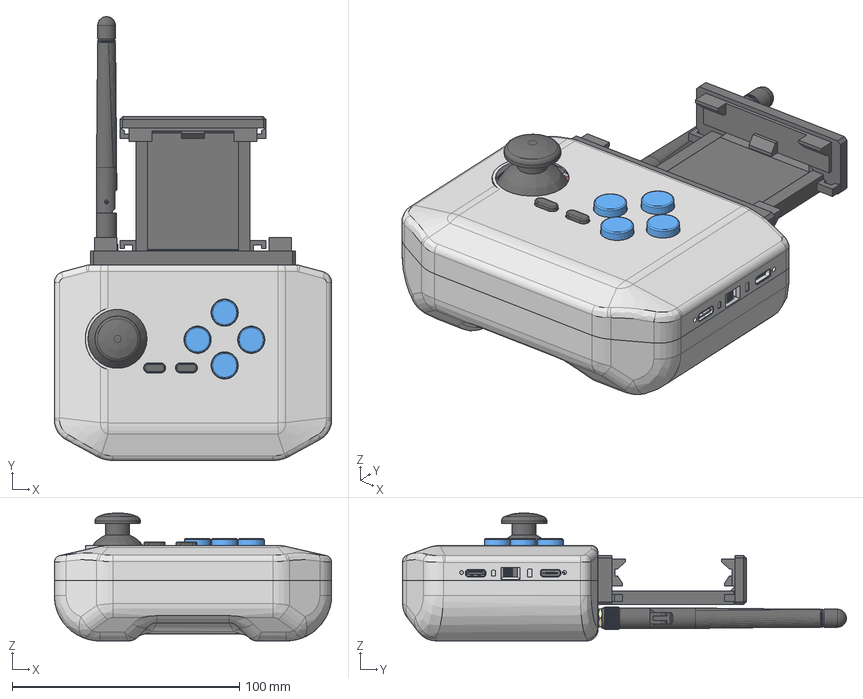
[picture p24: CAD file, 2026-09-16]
3d-print/remote/source/remote-v3.step
122.0 x 195.2 x 56.2 mm
BOSS-EXTRUDE14_8_
BOSS-EXTRUDE7_4_
BOSS-EXTRUDE7_3_
BOSS-EXTRUDE14_4_
BOSS-EXTRUDE14_2_
BOSS-EXTRUDE14_11_
BOSS-EXTRUDE7_7_
BOSS-EXTRUDE14_9_
BOSS-EXTRUDE14_3_
BOSS-EXTRUDE14_7_
MIRROR2
BOSS-EXTRUDE14_5_
BOSS-EXTRUDE14_12_
BOSS-EXTRUDE7_8_
BOSS-EXTRUDE7_1_
BOSS-EXTRUDE14_10_
BOSS-EXTRUDE7_9_
BOSS-EXTRUDE14_6_
BOSS-EXTRUDE14_1_
BOSS-EXTRUDE7_6_
BOSS-EXTRUDE7_2_
CUT-EXTRUDE5
BOSS-EXTRUDE7_5_
Shield
Pins x 2
U.FL-R-SMT-1_10_ v1
SS-12D06-G050
TP4056 Mini
BH311 AA Battery Holder_1
button-cap x 4
antenna-pad
small-button x 2
PCB
Button x 4
Stick
button-connector x 4
phone-holder-base
phone-holder-cap
2.4 GHz Antenna Base
2.4 GHz Antenna Top
BN 1036 1385542 Gewindeeinsatz zum Einlegen B-M4 x 6
91294A125_NO THREADS_Black-Oxide Alloy Steel Hex Drive Flat Head Scre w
91239A110_NO THREADS_Button Head Hex Drive Screw x 5

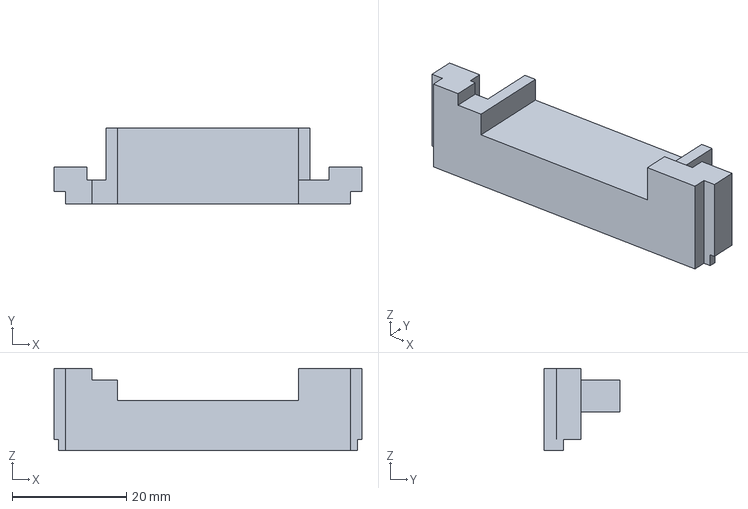
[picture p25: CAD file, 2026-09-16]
3d-print/rover/parts/gripper-shoulder-case-bottom.3mf
54.0 x 13.3 x 14.4 mm

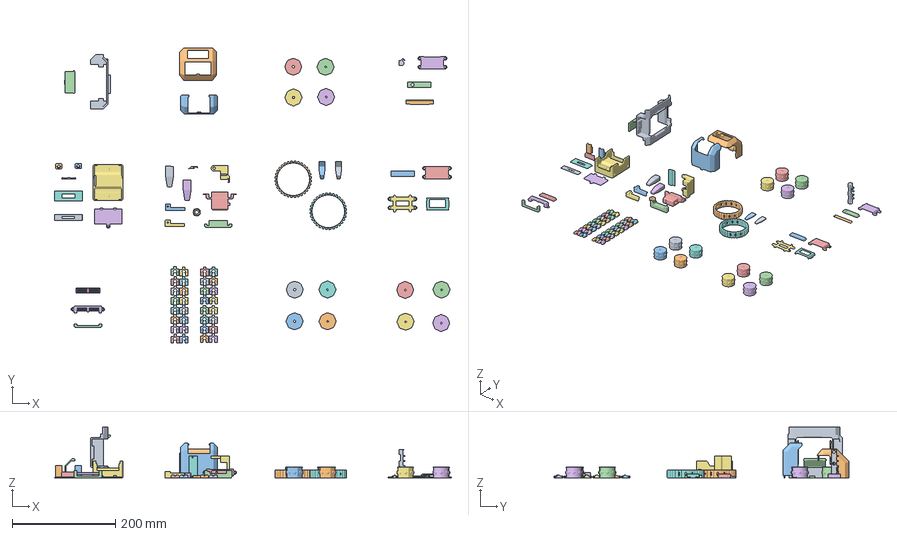
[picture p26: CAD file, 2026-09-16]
3d-print/rover/rover.3mf
770.7 x 573.2 x 99.0 mm
base
front
back
back-door
front-glass-blank
front-glass-light
front-glass-display-support
front-glass-display
light-mount
light-mount-cover
back-slot-plug
back-antenna-mount
battery-contact
cover
chasis
locker-big
locker-small
M4_adapter x 2
face-mount-bottom
splash-front
face-mount-top
case-base
case-cap
finger x 2
gear
rack x 2
case-bottom
case-top
finger-rubber x 2
track-normal x 16
track-reflected x 16
master-lock x 2
slave x 2
master x 2

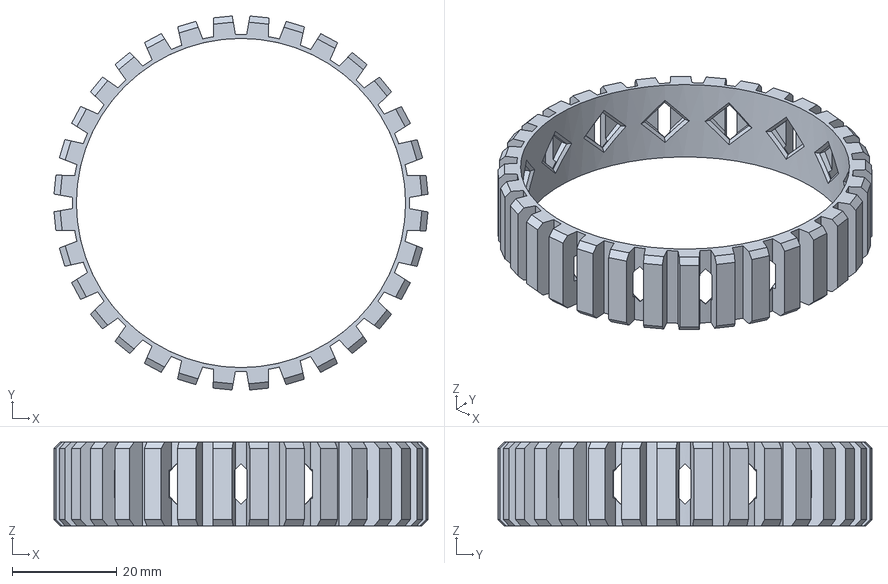
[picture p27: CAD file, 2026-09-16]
3d-print/rover/source/flex-track.step
71.6 x 71.6 x 16.0 mm

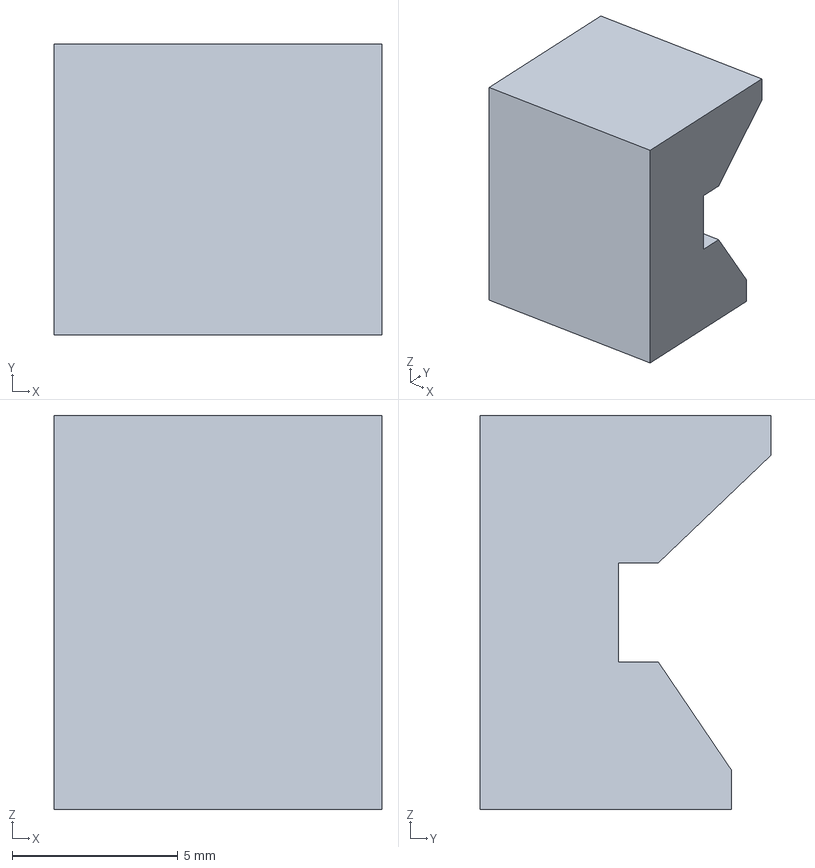
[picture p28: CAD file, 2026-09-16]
3d-print/remote/parts/phone-holder-base-rubber.3mf
9.90 x 8.79 x 11.9 mm

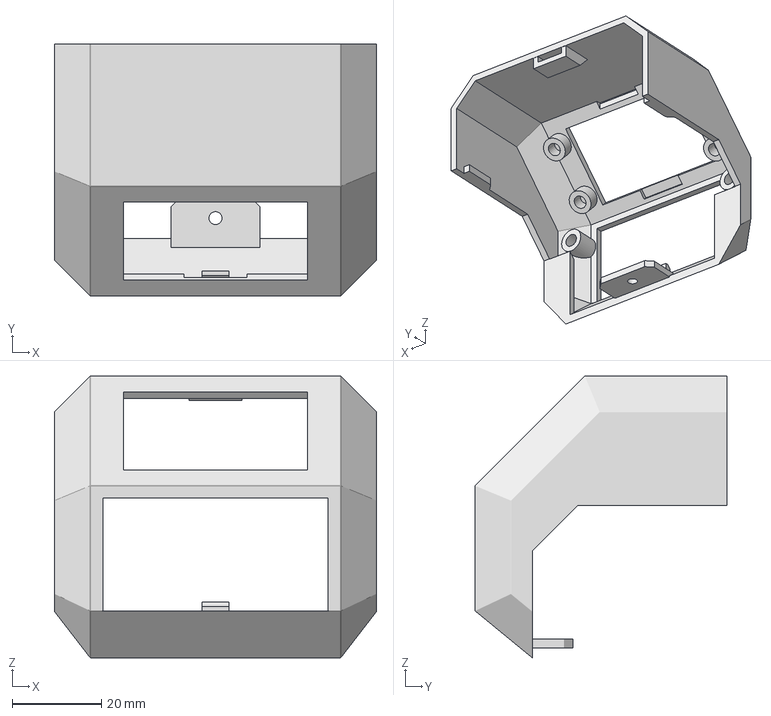
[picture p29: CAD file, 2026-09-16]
3d-print/rover/parts/body-front.3mf
72.0 x 56.3 x 63.0 mm

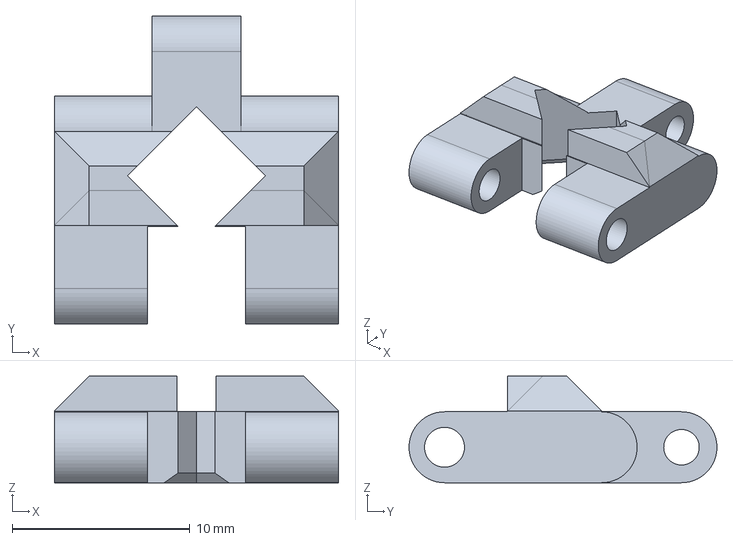
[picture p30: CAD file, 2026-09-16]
3d-print/rover/source/classic-track.step
16.0 x 17.4 x 6.00 mm

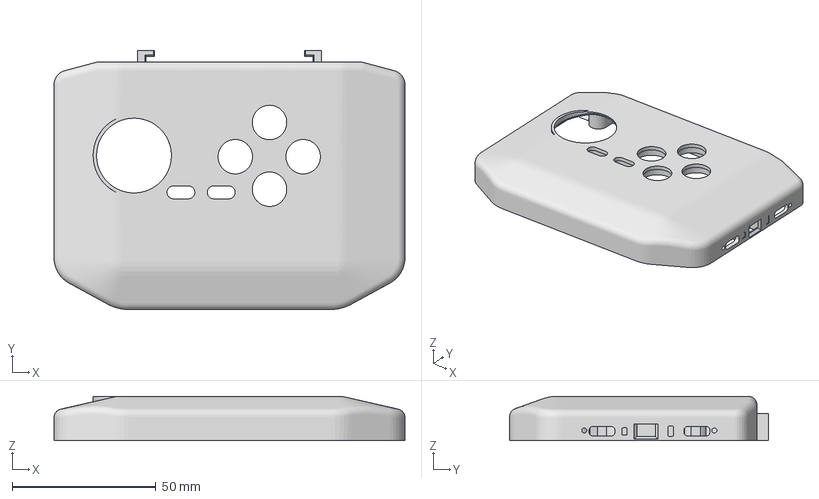
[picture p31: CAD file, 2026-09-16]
3d-print/remote/parts/body-top.3mf
122.0 x 90.0 x 15.5 mm

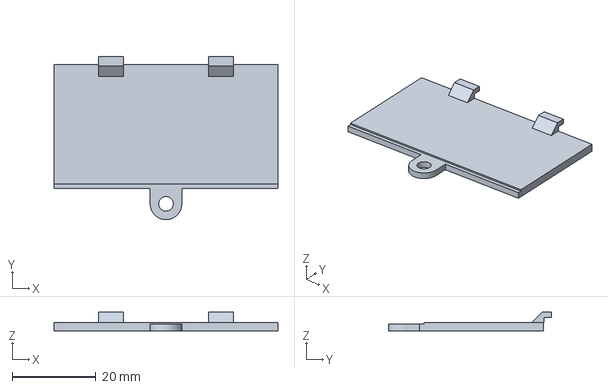
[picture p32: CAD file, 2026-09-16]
3d-print/rover/parts/battery-cover.3mf
53.6 x 39.1 x 4.50 mm

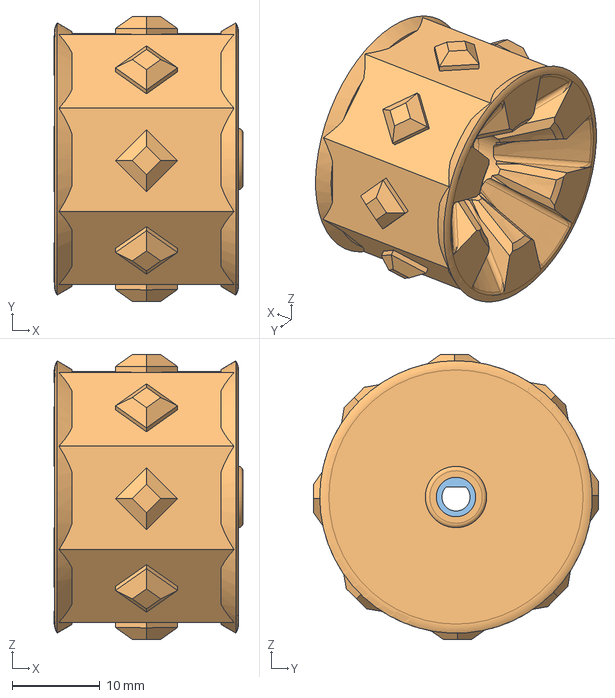
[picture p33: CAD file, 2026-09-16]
3d-print/rover/source/classic-wheels.step
21.5 x 32.5 x 32.5 mm

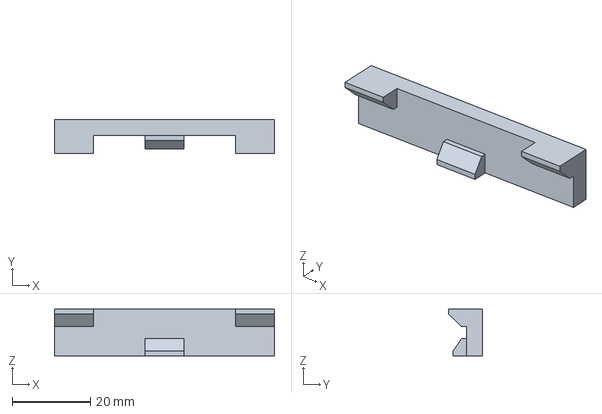
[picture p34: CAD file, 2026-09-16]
3d-print/remote/parts/phone-holder-cap-rubber.3mf
56.2 x 8.79 x 11.9 mm

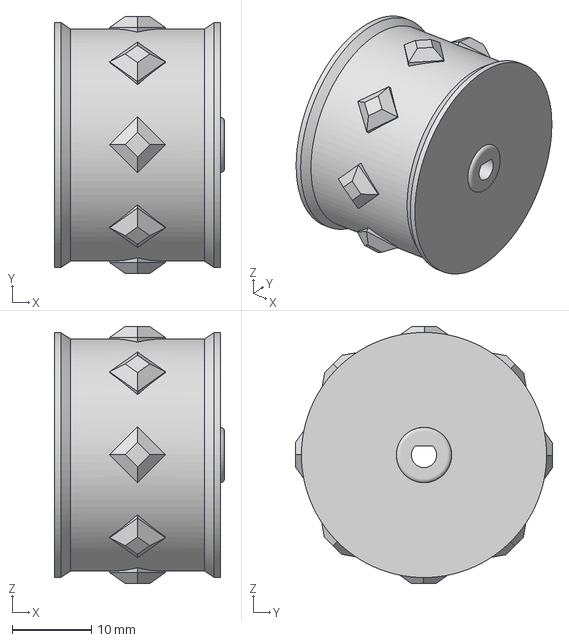
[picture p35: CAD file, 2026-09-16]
3d-print/rover/parts/flex-track-master-wheel.3mf
21.5 x 32.5 x 32.5 mm

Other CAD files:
3d-print/rover/source/flex-wheels.step
3d-print/remote/parts/button-connector.3mf
3d-print/rover/parts/front-glass-blank.3mf
3d-print/remote/parts/body-bottom.3mf
3d-print/remote/parts/antenna-pad.3mf
3d-print/remote/parts/phone-holder-base.3mf
3d-print/remote/parts/phone-holder-cap.3mf
3d-print/rover/parts/back-antenna-mount.3mf
3d-print/rover/parts/back-slot-plug.3mf
3d-print/rover/parts/battery-contact.3mf
3d-print/rover/parts/body-back-door.3mf
3d-print/rover/parts/body-back.3mf
3d-print/rover/parts/body-base.3mf
3d-print/rover/parts/chassis.3mf
3d-print/rover/parts/classic-track-master-wheel-lock.3mf
3d-print/rover/parts/classic-track-master-wheel.3mf
3d-print/rover/parts/classic-track-reflected.3mf
3d-print/rover/parts/classic-track-slave-wheel.3mf
3d-print/rover/parts/classic-track.3mf
3d-print/rover/parts/flex-track-master-wheel-lock.3mf
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

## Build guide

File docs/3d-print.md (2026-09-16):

3D printable parts
==================

| Image | Part name | File | Comments | Quantity |
|---|---|---|---|---|
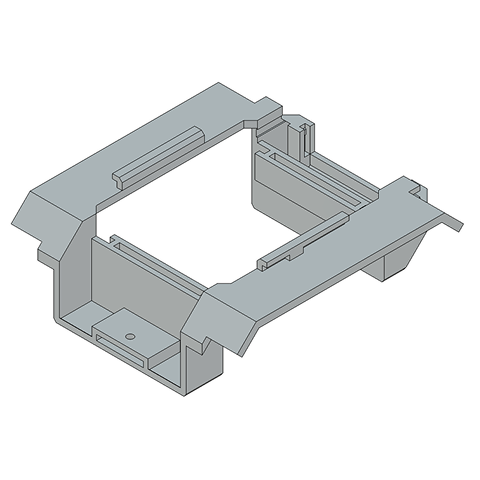
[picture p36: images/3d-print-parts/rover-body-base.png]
|  | Rover body base | [rover/parts/body-base.3mf](./../3d-print/rover/parts/body-base.3mf) |  | 1 |
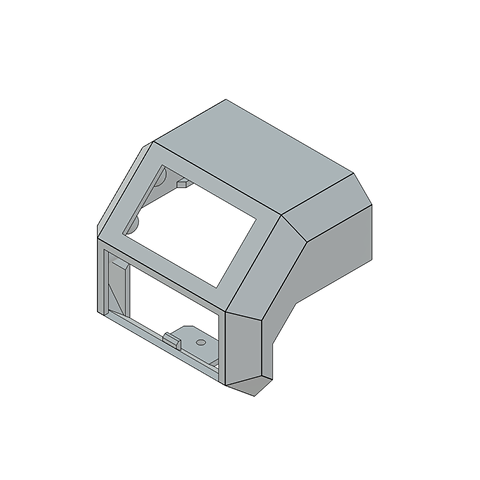
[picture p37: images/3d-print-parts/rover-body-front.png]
|  | Rover body front | [rover/parts/body-front.3mf](./../3d-print/rover/parts/body-front.3mf) |  | 1 |
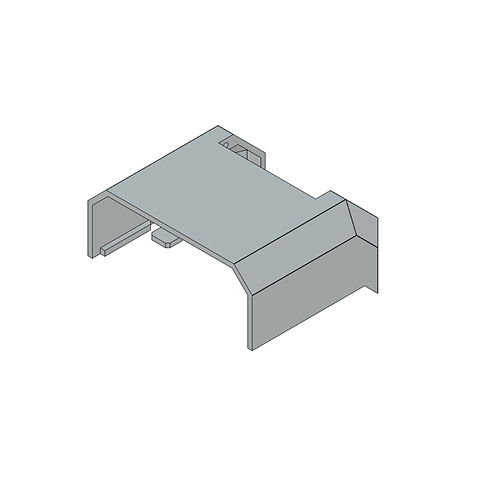
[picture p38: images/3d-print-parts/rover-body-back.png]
|  | Rover body back | [rover/parts/body-back.3mf](./../3d-print/rover/parts/body-back.3mf) |  | 1 |
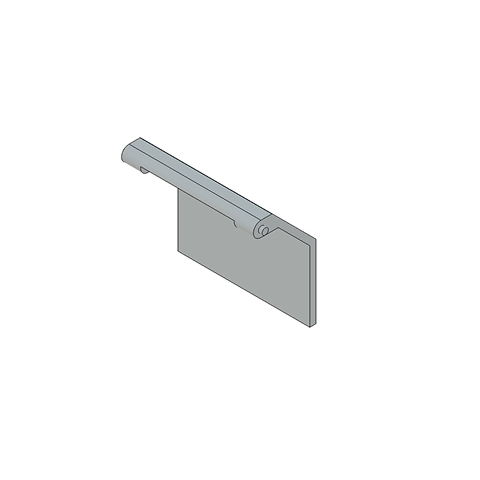
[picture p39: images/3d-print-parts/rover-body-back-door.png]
|  | Rover body back door | [rover/parts/body-back-door.3mf](./../3d-print/rover/parts/body-back-door.3mf) |  | 1 |
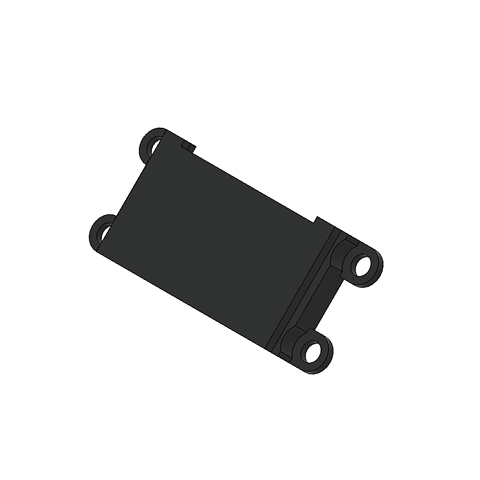
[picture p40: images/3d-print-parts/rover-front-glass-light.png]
|  | Rover front glass, variant with light mount niche | [rover/parts/front-glass-light.3mf](./../3d-print/rover/parts/front-glass-light.3mf) | Recommended | 1 |
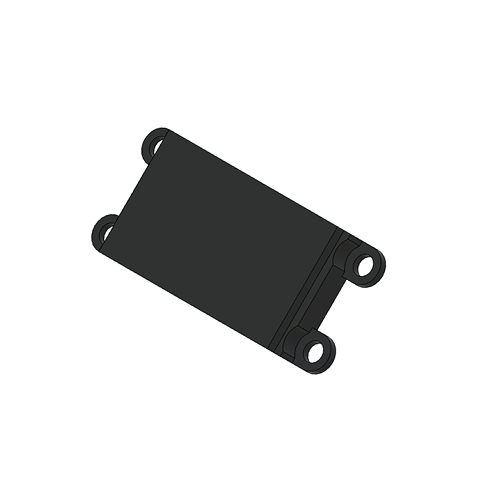
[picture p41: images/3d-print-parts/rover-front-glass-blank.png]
|  | Rover front glass, blank variant | [rover/parts/front-glass-blank.3mf](./../3d-print/rover/parts/front-glass-blank.3mf) | Alternative | 1 |
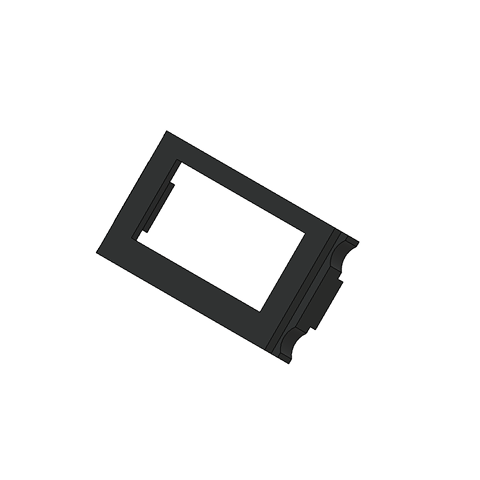
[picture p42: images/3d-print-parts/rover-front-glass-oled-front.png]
|  | Rover front glass, variant for OLED screen, front part | [rover/parts/front-glass-oled-front.3mf](./../3d-print/rover/parts/front-glass-oled-front.3mf) | Alternative | 1 |
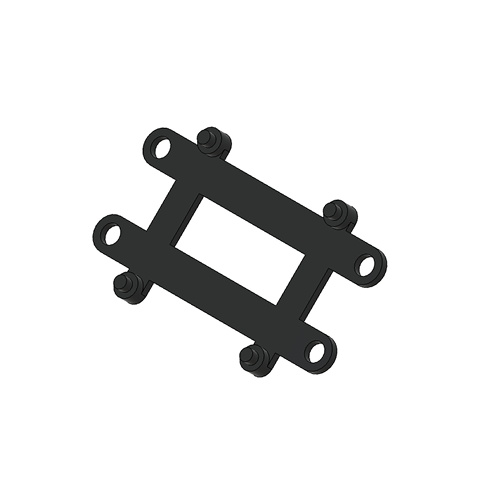
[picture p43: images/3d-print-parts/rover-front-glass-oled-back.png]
|  | Rover front glass, variant for OLED screen, back part | [rover/parts/front-glass-oled-back.3mf](./../3d-print/rover/parts/front-glass-oled-back.3mf) | Alternative | 1 |
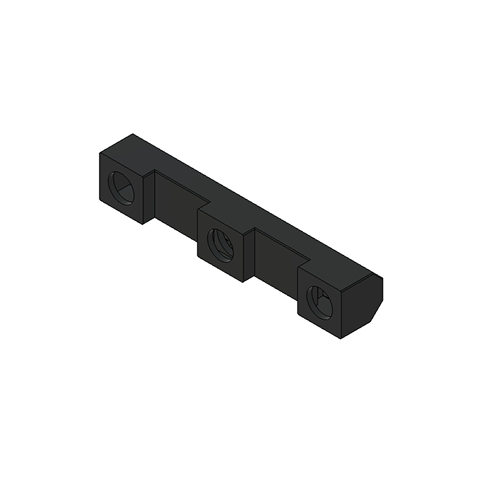
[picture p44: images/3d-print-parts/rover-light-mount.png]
|  | Rover light mount | [rover/parts/light-mount.3mf](./../3d-print/rover/parts/light-mount.3mf) | Recommended | 1 |
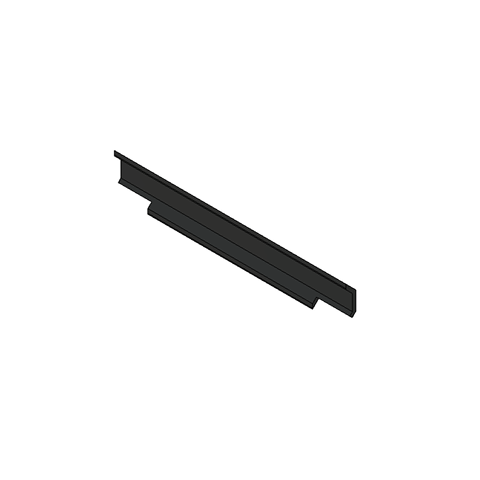
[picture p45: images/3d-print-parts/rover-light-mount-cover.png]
|  | Rover light mount cover | [rover/parts/light-mount-cover.3mf](./../3d-print/rover/parts/light-mount-cover.3mf) | Recommended | 1 |
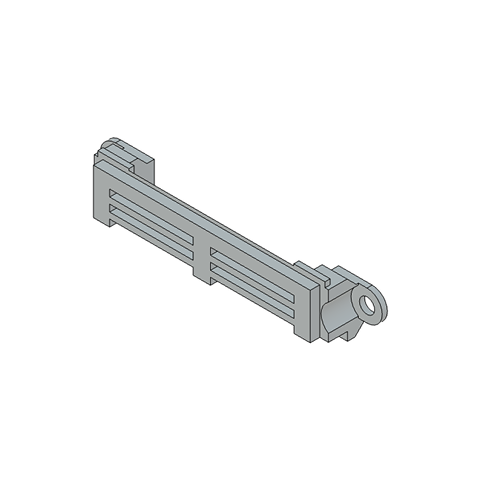
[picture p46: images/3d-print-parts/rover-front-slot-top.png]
|  | Rover front add-on slot, top part | [rover/parts/front-slot-top.3mf](./../3d-print/rover/parts/front-slot-top.3mf) | Alternative to gripper | 1 |
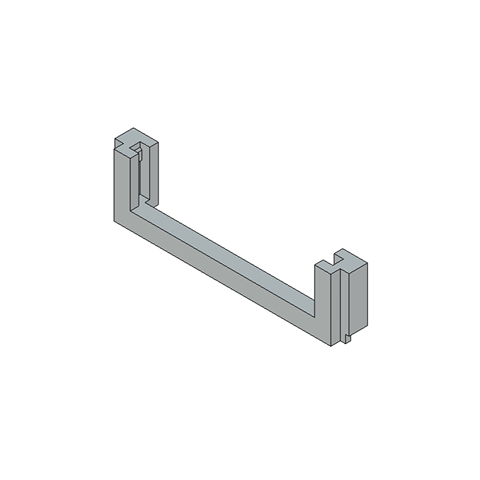
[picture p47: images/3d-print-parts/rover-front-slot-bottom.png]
|  | Rover front add-on slot, bottom part | [rover/parts/front-slot-bottom.3mf](./../3d-print/rover/parts/front-slot-bottom.3mf) | Alternative to gripper | 1 |
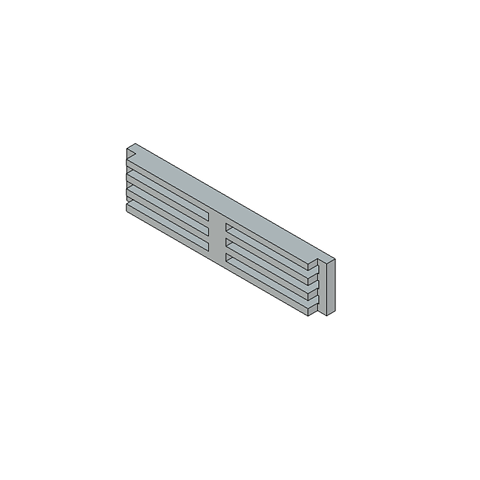
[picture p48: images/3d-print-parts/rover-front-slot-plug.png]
|  | Rover front add-on slot plug | [rover/parts/front-slot-plug.3mf](./../3d-print/rover/parts/front-slot-plug.3mf) | Alternative to gripper | 1 |
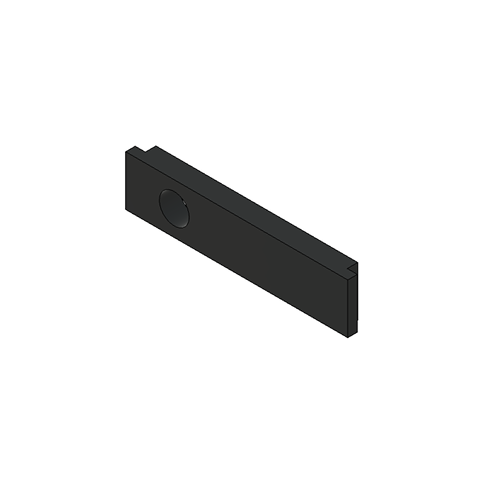
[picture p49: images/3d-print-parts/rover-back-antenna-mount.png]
|  | Rover back antenna mount | [rover/parts/back-antenna-mount.3mf](./../3d-print/rover/parts/back-antenna-mount.3mf) | Recommended for video streaming | 1 |
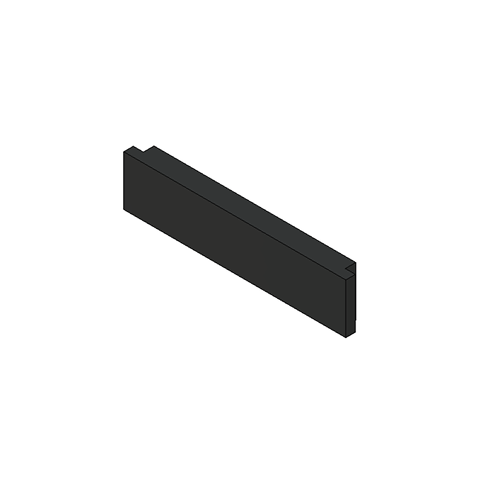
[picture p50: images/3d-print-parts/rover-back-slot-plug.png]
|  | Rover back add-on slot plug | [rover/parts/back-slot-plug.3mf](./../3d-print/rover/parts/back-slot-plug.3mf) | Alternative | 1 |
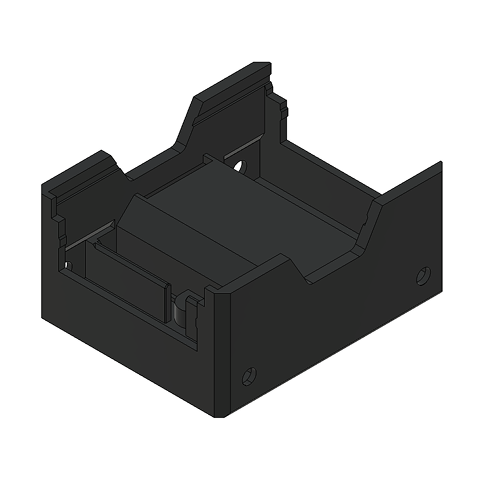
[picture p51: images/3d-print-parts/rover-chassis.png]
|  | Rover chassis | [rover/parts/chassis.3mf](./../3d-print/rover/parts/chassis.3mf) | Remixed from [thingiverse.com/thing:2829401](https://www.thingiverse.com/thing:2829401) | 1 |
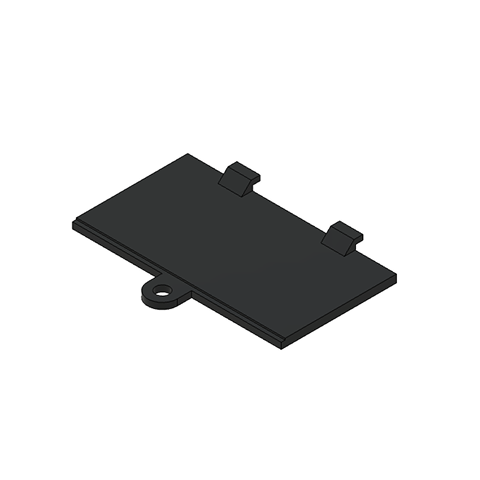
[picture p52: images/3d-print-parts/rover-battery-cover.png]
|  | Rover battery cover | [rover/parts/battery-cover.3mf](./../3d-print/rover/parts/battery-cover.3mf) |  | 1 |
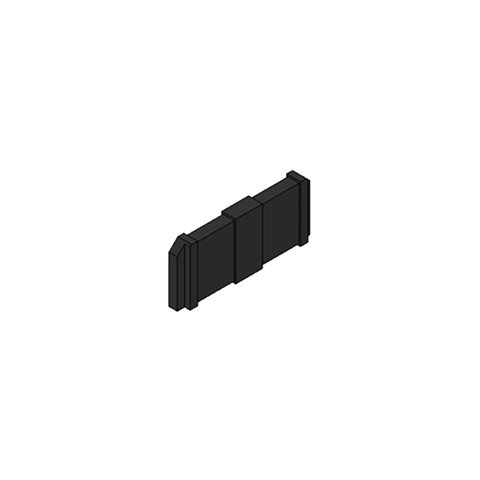
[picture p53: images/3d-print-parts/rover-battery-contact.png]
|  | Rover battery contact pad | [rover/parts/battery-contact.3mf](./../3d-print/rover/parts/battery-contact.3mf) |  | 1 |
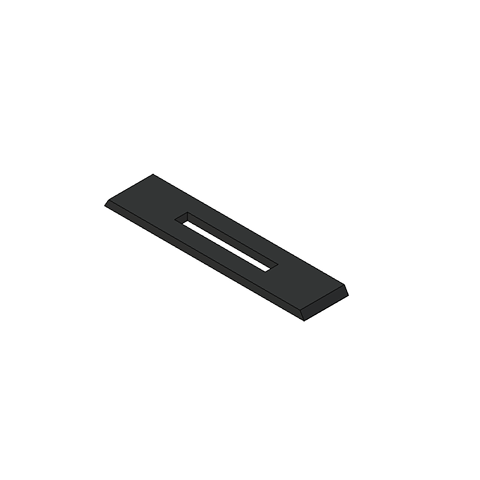
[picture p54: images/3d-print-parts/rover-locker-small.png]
|  | Rover motor niche locker | [rover/parts/locker-small.3mf](./../3d-print/rover/parts/locker-small.3mf) |  | 1 |
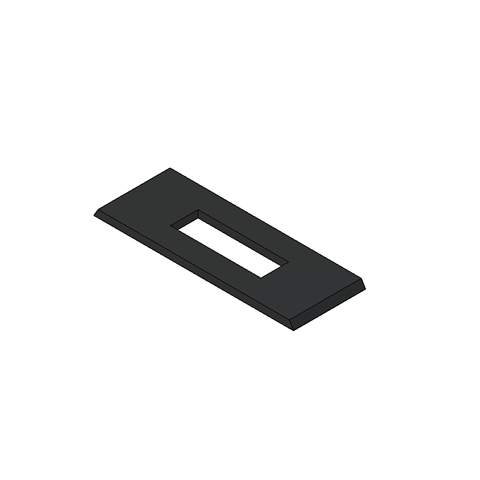
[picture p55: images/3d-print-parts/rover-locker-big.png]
|  | Rover slave wheel adapter niche locker | [rover/parts/locker-big.3mf](./../3d-print/rover/parts/locker-big.3mf) |  | 1 |
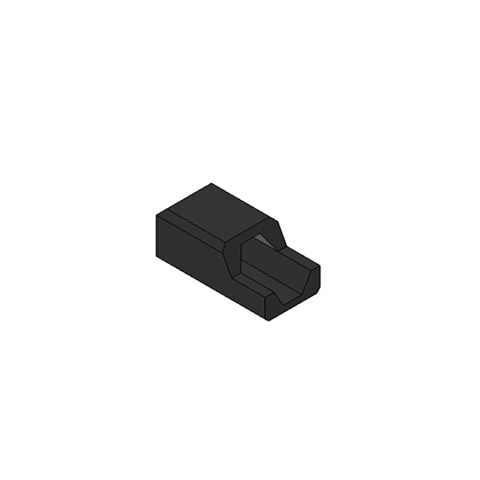
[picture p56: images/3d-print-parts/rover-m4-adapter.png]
|  | Rover slave wheel adapter | [rover/parts/m4-adapter.3mf](./../3d-print/rover/parts/m4-adapter.3mf) | Remixed from [thingiverse.com/thing:2829401](https://www.thingiverse.com/thing:2829401) | 2 |
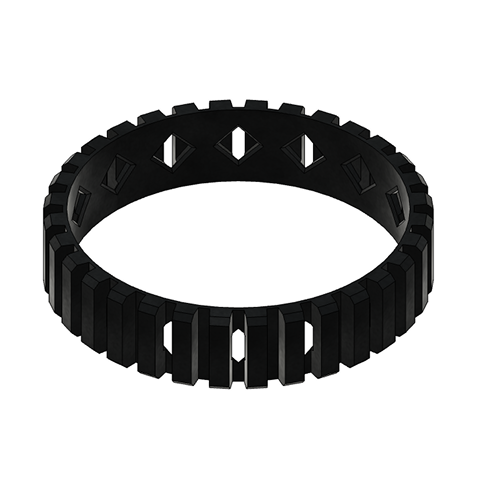
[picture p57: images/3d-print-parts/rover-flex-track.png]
|  | Rover flex track | [rover/parts/flex-track.3mf](./../3d-print/rover/parts/flex-track.3mf) | Recommended | 2 |
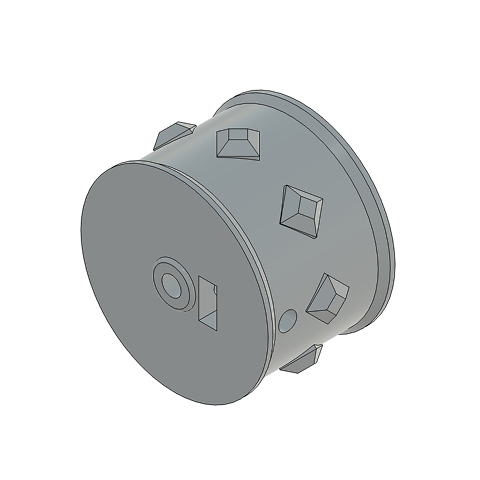
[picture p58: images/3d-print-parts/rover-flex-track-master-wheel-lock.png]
|  | Rover master wheel with lock for flex track | [rover/parts/flex-track-master-wheel-lock.3mf](./../3d-print/rover/parts/flex-track-master-wheel-lock.3mf) | Recommended, remixed from [thingiverse.com/thing:4686208](https://www.thingiverse.com/thing:4686208) | 2 |
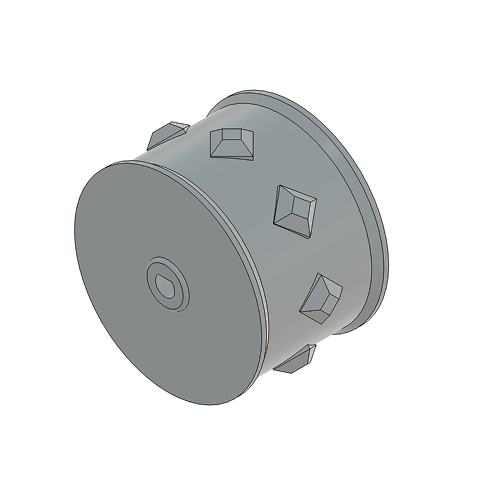
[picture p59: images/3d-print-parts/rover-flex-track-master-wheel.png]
|  | Rover master wheel for flex track | [rover/parts/flex-track-master-wheel.3mf](./../3d-print/rover/parts/flex-track-master-wheel.3mf) | Alternative, remixed from [thingiverse.com/thing:4686208](https://www.thingiverse.com/thing:4686208) | 2 |
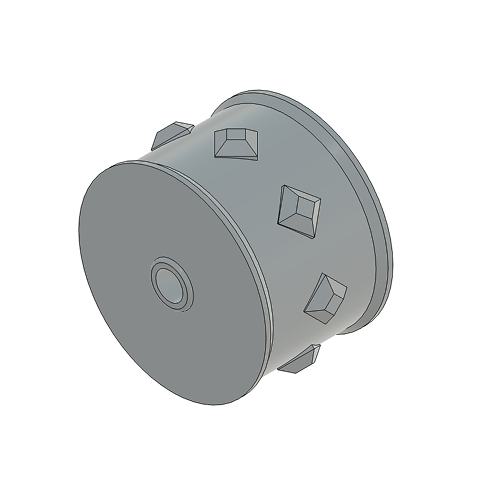
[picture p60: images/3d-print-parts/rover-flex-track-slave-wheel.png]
|  | Rover slave wheel for flex track | [rover/parts/flex-track-slave-wheel.3mf](./../3d-print/rover/parts/flex-track-slave-wheel.3mf) | Recommended, remixed from [thingiverse.com/thing:4686208](https://www.thingiverse.com/thing:4686208) | 2 |
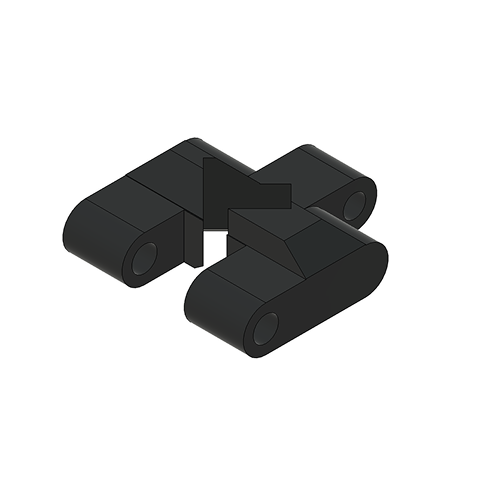
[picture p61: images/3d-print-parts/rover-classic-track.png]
|  | Rover classic track | [rover/parts/classic-track.3mf](./../3d-print/rover/parts/classic-track.3mf) | Alternative, copied from [thingiverse.com/thing:2662828](https://www.thingiverse.com/thing:2662828) | 16 |
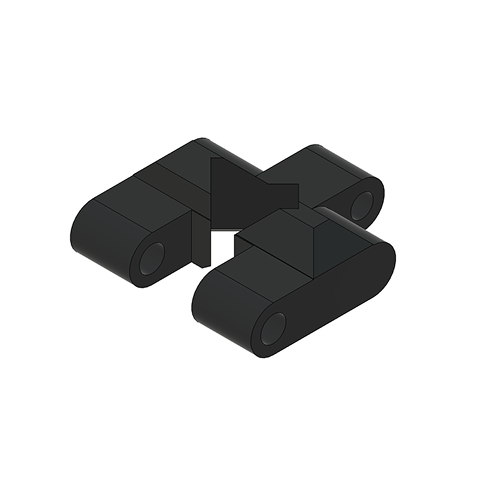
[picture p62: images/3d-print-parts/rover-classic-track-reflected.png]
|  | Rover classic track reflected | [rover/parts/classic-track-reflected.3mf](./../3d-print/rover/parts/classic-track-reflected.3mf) | Alternative, remixed from [thingiverse.com/thing:2662828](https://www.thingiverse.com/thing:2662828) | 16 |
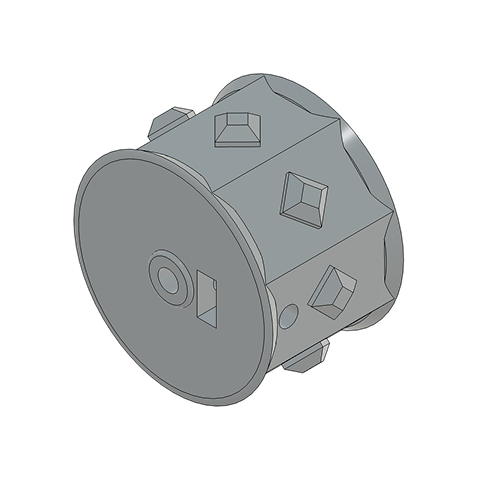
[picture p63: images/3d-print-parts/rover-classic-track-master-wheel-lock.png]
|  | Rover master wheel with lock for classic track | [rover/parts/classic-track-master-wheel-lock.3mf](./../3d-print/rover/parts/classic-track-master-wheel-lock.3mf) | Alternative, remixed from [thingiverse.com/thing:4686208](https://www.thingiverse.com/thing:4686208) | 2 |
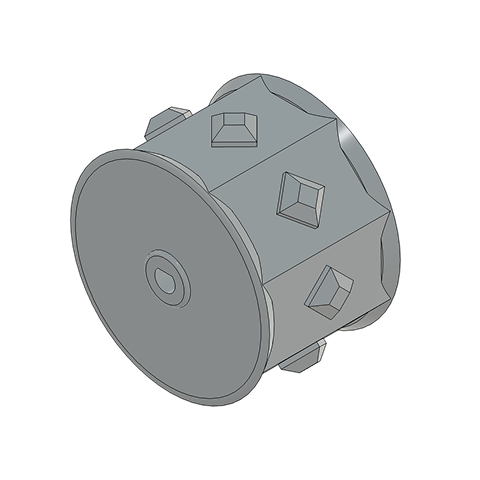
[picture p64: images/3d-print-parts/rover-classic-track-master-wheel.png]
|  | Rover master wheel for classic track | [rover/parts/classic-track-master-wheel.3mf](./../3d-print/rover/parts/classic-track-master-wheel.3mf) | Alternative, remixed from [thingiverse.com/thing:4686208](https://www.thingiverse.com/thing:4686208) | 2 |
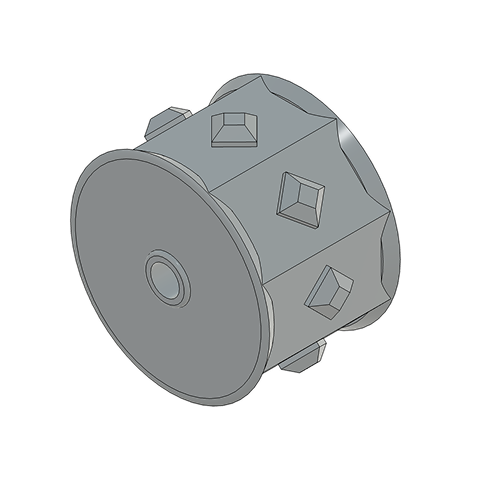
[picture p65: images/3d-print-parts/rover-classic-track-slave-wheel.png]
|  | Rover slave wheel for classic track | [rover/parts/classic-track-slave-wheel.3mf](./../3d-print/rover/parts/classic-track-slave-wheel.3mf) | Alternative, remixed from [thingiverse.com/thing:4686208](https://www.thingiverse.com/thing:4686208) | 2 |
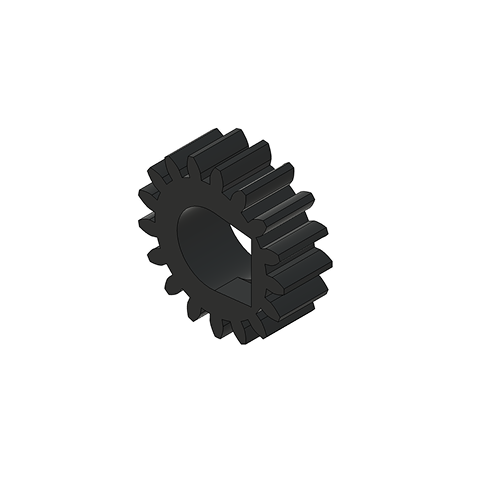
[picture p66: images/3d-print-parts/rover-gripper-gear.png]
|  | Rover gripper gear | [rover/parts/gripper-gear.3mf](./../3d-print/rover/parts/gripper-gear.3mf) |  | 1 |
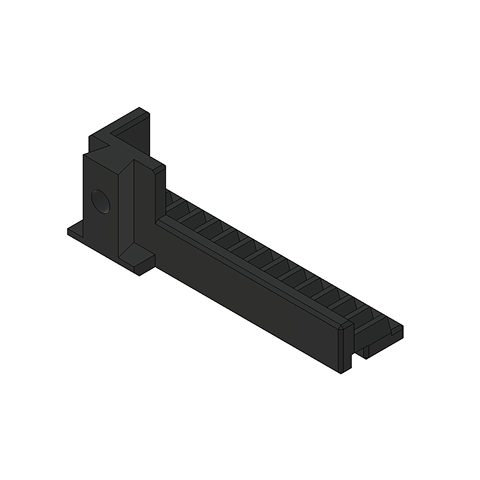
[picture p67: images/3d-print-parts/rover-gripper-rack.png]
|  | Rover gripper rack | [rover/parts/gripper-rack.3mf](./../3d-print/rover/parts/gripper-rack.3mf) |  | 2 |
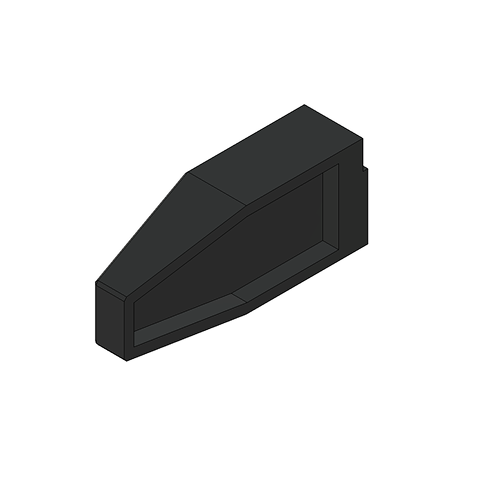
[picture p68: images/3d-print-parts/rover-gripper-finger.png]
|  | Rover gripper finger | [rover/parts/gripper-finger.3mf](./../3d-print/rover/parts/gripper-finger.3mf) |  | 2 |
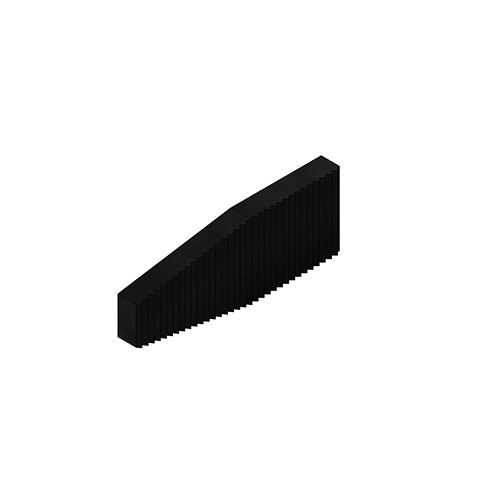
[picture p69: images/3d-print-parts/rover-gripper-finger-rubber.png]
|  | Rover gripper finger rubber insert | [rover/parts/gripper-finger-rubber.3mf](./../3d-print/rover/parts/gripper-finger-rubber.3mf) |  | 2 |
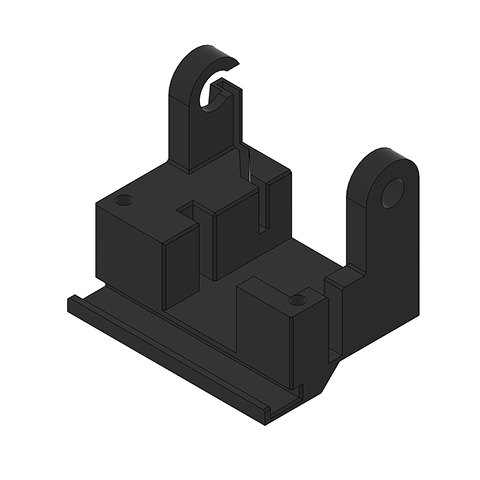
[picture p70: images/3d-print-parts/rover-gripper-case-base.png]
|  | Rover gripper case base | [rover/parts/gripper-case-base.3mf](./../3d-print/rover/parts/gripper-case-base.3mf) |  | 1 |
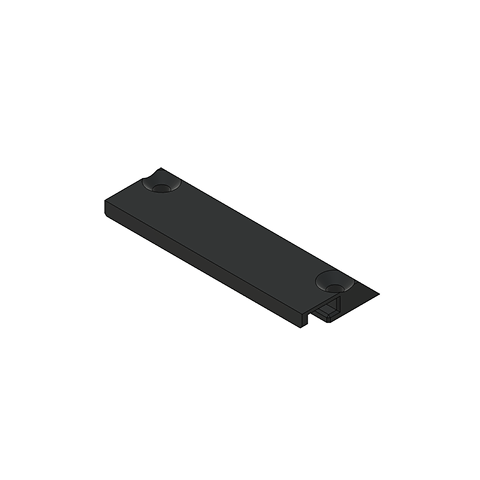
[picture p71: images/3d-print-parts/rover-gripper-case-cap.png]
|  | Rover gripper case cap | [rover/parts/gripper-case-cap.3mf](./../3d-print/rover/parts/gripper-case-cap.3mf) |  | 1 |
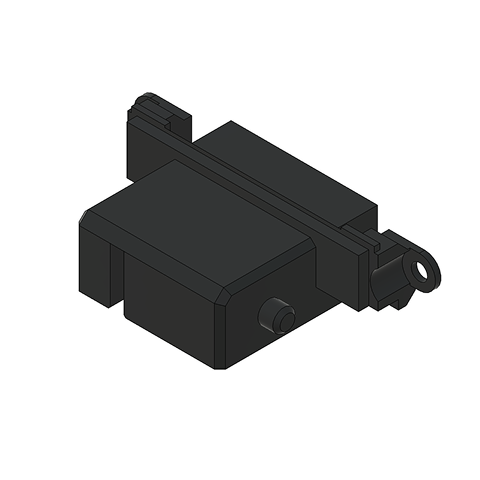
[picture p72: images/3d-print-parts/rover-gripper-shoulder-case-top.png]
|  | Rover gripper shoulder case, top part | [rover/parts/gripper-shoulder-case-top.3mf](./../3d-print/rover/parts/gripper-shoulder-case-top.3mf) |  | 1 |
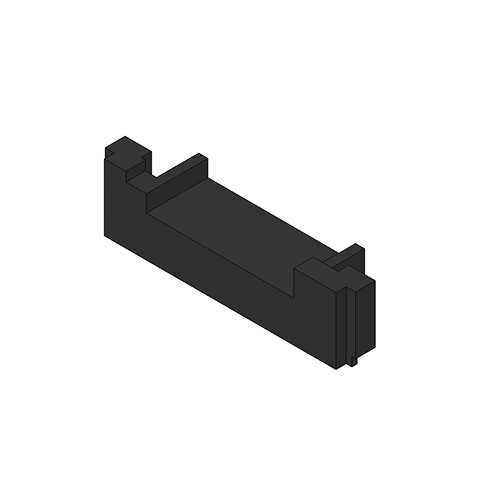
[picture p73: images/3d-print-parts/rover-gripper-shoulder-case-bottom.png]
|  | Rover gripper shoulder case, bottom part | [rover/parts/gripper-shoulder-case-bottom.3mf](./../3d-print/rover/parts/gripper-shoulder-case-bottom.3mf) |  | 1 |
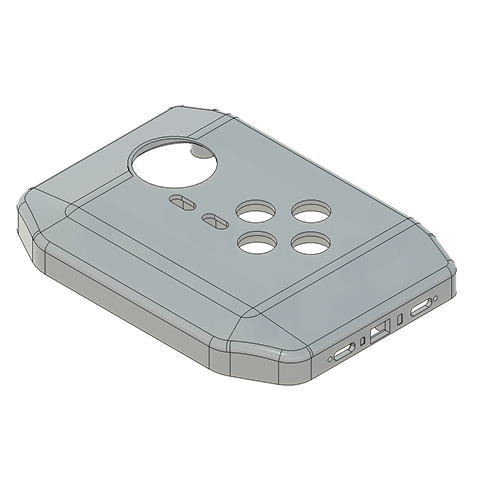
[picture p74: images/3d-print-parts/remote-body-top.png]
|  | Remote body, top part | [remote/parts/body-top.3mf](./../3d-print/remote/parts/body-top.3mf) |  | 1 |
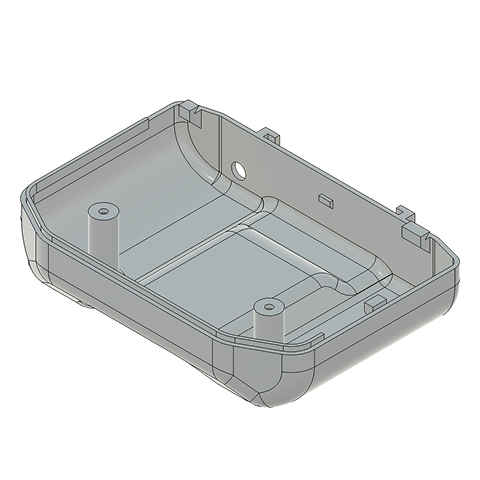
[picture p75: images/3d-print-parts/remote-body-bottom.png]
|  | Remote body, bottom part | [remote/parts/body-bottom.3mf](./../3d-print/remote/parts/body-bottom.3mf) |  | 1 |
|  | Remote button connector | [remote/parts/button-connector.3mf](./../3d-print/remote/parts/button-connector.3mf) |  | 4 |
|  | Remote small button | [remote/parts/small-button.3mf](./../3d-print/remote/parts/small-button.3mf) |  | 2 |
|  | Remote internal antenna pad | [remote/parts/antenna-pad.3mf](./../3d-print/remote/parts/antenna-pad.3mf) | Alternative | 1 |
|  | Remote phone holder base | [remote/parts/phone-holder-base.3mf](./../3d-print/remote/parts/phone-holder-base.3mf) |  | 1 |
|  | Remote phone holder cap | [remote/parts/phone-holder-cap.3mf](./../3d-print/remote/parts/phone-holder-cap.3mf) |  | 1 |
|  | Remote phone holder base rubber | [remote/parts/phone-holder-base-rubber.3mf](./../3d-print/remote/parts/phone-holder-base-rubber.3mf) |  | 2 |
|  | Remote phone holder cap rubber | [remote/parts/phone-holder-cap-rubber.3mf](./../3d-print/remote/parts/phone-holder-cap-rubber.3mf) |  | 1 |

The rover body and chassis are compatible and interchangeable with parts from the original SMARS robot project and most of its add-ons.
All parts are designed to stay compatible with the existing SMARS robot project, preserving its modularity and extensibility.
All parts except the flexible ones are designed to be printed in PETG on modern, precise 3D printers, so tolerances are minimal.

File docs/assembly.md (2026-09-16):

Assembly
========

This guide walks through the assembly of the SMARS ROVER, step by step.

Part names follow the [Parts list](parts-list.md) and the [3D printable parts](3d-print.md) list. Wiring references the [rover connection scheme](./../images/rover-connection-scheme.png) and the markings printed on the custom PCB.

> **Warning: never power an ESP32 board without an antenna connected.** This applies to both the rover and the remote, and to power from USB as well as from the battery — transmitting without an antenna can damage the board. Plug an antenna in before the first power-up and leave it connected.

Rover
-----

### Step 1. Dry run and firmware (optional, recommended)

Before soldering anything permanently, it is worth checking that the electronics and the firmware work together.

**Warning:** connect an antenna to both ESP32 boards before you power them up for the first time.

1. Assemble the rover electronics on a breadboard, without soldering, following the rover connection scheme.

   Rover connection scheme

2. Assemble the remote electronics on a breadboard the same way, following the remote connection scheme.

   Remote connection scheme

3. Flash the `esp-mac` sketch to both ESP32 boards to read their MAC addresses. Alternatively, use [ESPConnect](https://thelastoutpostworkshop.github.io/ESPConnect/).
4. Put the remote's MAC address into the rover sketch (`software/rover-esp`, `controllerMac` in `src/main.cpp`) and flash it to the rover.
5. Put the rover's MAC address into the remote sketch (`software/remote-webcam`, `robot_mac` in `src/main.c`) and flash it to the remote.

### Step 2. Motor wiring

1. Prepare two pairs of wires, 12–15 cm long, with female JST XH2.54 crimp contacts on one end. Do not insert the contacts into the connector housings yet.

   If you are using ready-made wires with assembled connectors, either pull the contacts out of the housing or pass the free ends through the motor niche locker before soldering — the slot in the locker is too narrow for an assembled connector to pass through.

2. Recommended: slide heat shrink tubing onto the wires.
3. Solder the wires to the N20 motors. Polarity is not critical here, it can be corrected in the firmware.

   Motor leads soldered, twisted and heat-shrunk

4. Optional: solder a 10nF capacitor directly across the motor terminals.

   If you fit the capacitors, it is recommended to wrap the whole terminal area in Kapton tape. The motor niche leaves very little room, and it is easy to short the two motors against each other.

   Motors with 10nF capacitors and terminals wrapped in Kapton tape

5. Recommended: twist each pair of wires into a spiral.
6. Shrink the heat shrink tubing, if used.

### Step 3. Battery contacts

1. Prepare two wires 12–15 cm long and one wire 20–23 cm long, with female JST XH2.54 crimp contacts on one end.

   Recommended: use wires of different colours so the polarity stays easy to tell apart.

2. Cut two nickel strips for the positive and negative battery contacts and wrap them around the 3D-printed battery contact pad.
3. Cut one more nickel strip for the middle contact pad. Adjust its length by test-fitting it in the chassis.
4. Insert the battery contact pad and the middle contact pad into the chassis.
5. Put the batteries into the battery tray and check that they are held firmly and make reliable contact. Bend the strips to adjust the tension if needed.
6. Take the batteries back out.

   **Warning:** never put batteries against contacts that already have wires soldered to them while the connector is not yet assembled. The loose wire ends short the battery very easily.

7. To make the next steps easier, take the battery contact pad and the middle contact pad back out of the chassis.
8. Recommended: slide heat shrink tubing onto the wires.
9. Solder the two short wires to the positive and negative contacts, and the long wire to the middle contact.

   Battery contact pad and middle contact pad with soldered wires

   The same contacts with heat shrink tubing applied

10. Put both contact pads back into the chassis and route the wires to the outside of the battery tray. Run the middle contact wire through the dedicated channel in the battery tray.
11. Recommended: twist the wires into a spiral.
12. Assemble the 3-pin JST connector following the custom PCB markings. **The pin order is crucial** — B+, BM (middle) and B− must match the `BAT` connector on the PCB.
13. Shrink the heat shrink tubing, if used.

    Contacts installed in the chassis with the 3-pin battery connector assembled

### Step 4. Chassis assembly

1. Heat-set an M3 insert nut for the battery cover screw.

   M3 insert nut heat-set into the chassis

2. Place the motors into the smaller niche of the chassis. Mounted this way, the rear wheels become the master (driven) ones, which is the recommended layout.
3. Pass the wire ends with the crimp contacts through the motor niche locker.
4. Press the motor niche locker into place. It goes in tight, that is expected.
5. Assemble the 2-pin JST connectors on the motor wires.

   Motors installed in the chassis with the motor niche locker in place

6. Recommended, to reduce backlash in the slave wheels:

   * Mount the slave wheels in their final position using the slave wheel adapters, M4x30 screws and M4 self-locking nuts.
   * Fill the slave wheel adapter niche with hot glue and close it with the slave wheel adapter niche locker.
   * Wait for the glue to set, then unscrew the M4x30 screws and take the wheels off again.

   Slave wheel adapter niche filled with hot glue and closed with the locker

7. Push the master wheels onto the motor shafts. If you are using the wheels with a lock, secure each wheel with an M3x12 set screw and an M3 square nut.
8. Fit the tracks.
9. Put the slave wheels back in place and fasten them with the M4x30 screws.

   Completed chassis with wheels and tracks fitted

### Step 5. Light and camera mount

The light and the camera are optional. If you are not building them, use the blank front glass or the front glass variant for an OLED screen in the next step, instead of the front glass with the light mount niche. Fitting an OLED 1.3" 128x64 I2C screen is mechanically possible — though not together with the light and the camera — but no firmware or instructions are provided for it.

1. If you are using the custom PCB, break the light board off the main board. Otherwise, use a piece of prototype board as the light board (no layout is provided for that option).
2. Solder two 100Ω resistors and two Piranha LEDs to the light board.
3. Prepare two wires 12–15 cm long with a 2-pin female JST XH2.54 connector on one end.
4. Solder the wires to the light board, observing the polarity shown in the rover connection scheme.

   Assembled light board with two LEDs, two resistors and a 2-pin connector

5. Insert the camera into the light mount.
6. Insert the light board into the light mount.

   Camera and light board fitted into the light mount

7. Apply a little hot glue to the back of the light board and close the light mount cover.

   Light mount closed with its cover

8. Connect the camera to the camera sensor board of the XIAO ESP32-S3 Sense.

   Camera connected to the camera sensor board

### Step 6. Body front assembly

Assembling the gripper requires the servos to be powered at least once, so that their gears take their initial positions. The easiest way to do this is to drive them from the assembled rover, so the gripper is left until step 9. If you have already powered the servos with the rover firmware — during step 1, for example — you can assemble the gripper now (step 9) and mount it to the body front right away.

1. Heat-set six M3 insert nuts into the body front.

   Six M3 insert nuts heat-set into the body front

2. Place the light mount into the front glass opening of the body front.
3. Place the front glass with the light mount niche into the same opening, over the light mount.
4. Secure the front glass with four M3x5 screws with pad.

   Front glass and light mount installed in the body front

5. Optional: until the gripper is assembled, you can temporarily fit the front add-on slot parts (top, bottom and plug) and secure them with M3x5 screws with pad.

   Front add-on slot parts temporarily fitted

### Step 7. Main PCB

If you are not using the custom PCB, a Prototype PCB Uno R3 can be used instead (no layout is provided for that option).

1. Solder the resistors, the 220µF capacitor, the Schottky diode and the transistor, following the markings on the PCB.

   Do not fit the 100µF capacitor unless you run into problems powering the servos — it is a fallback option.

2. Solder the male JST XH2.54 connectors.
3. Solder the power switch and the pin headers.
4. Solder the female headers.

   Populated main PCB, component side

   Populated main PCB, solder side

5. Solder pin headers to the modules.
6. Recommended: stick two aluminum heatsinks to the XIAO ESP32-S3 Sense.
7. Plug the modules into the PCB.
8. Fix the charger module in place with hot glue.

   Main PCB with all modules plugged in

### Step 8. Body assembly

1. Put the body base onto the chassis.

   Body base placed on the chassis

2. Insert the main PCB into its slot and pass the motor and battery wires through the side openings.
3. Connect the motors and the battery to the PCB.

   Main PCB installed in the body base with motors and battery connected

4. Attach the assembled body front to the body base.
5. Connect the light to its connector on the PCB.
6. Connect the camera sensor board to the XIAO ESP32-S3 Sense.
7. Secure the body front with an M3x5 screw with pad.

   Body front attached, light and camera connected

8. Install the batteries, close the battery cover and secure it with an M3x5 screw with pad.
9. Connect an antenna to the IPEX connector on the XIAO ESP32-S3 Sense, then switch the rover on. The LEDs on the ESP32 and on the motor driver (red) should light up.

   **Warning:** never power the board without an antenna connected, not even briefly. The antenna is only mounted in its final place in step 10, so for now simply plug it into the board and leave it loose.

### Step 9. Gripper assembly

1. If you have not done it yet, put the remote's MAC address into the rover sketch (`rover-esp`) and flash it to the rover.
2. Connect both servos to the PCB and turn the rover on, with the antenna still connected. The servo gears should move to their initial positions.

   Both servos connected to the PCB of the assembled rover

3. Turn the rover off and disconnect the servos.
4. Detach the body front from the body base, and remove the front add-on slot parts if they are fitted.
5. Insert a rubber insert into a finger.
6. Attach the finger to a rack and secure it with an M3x20 flat head screw.
7. Slide the rack with the finger into the rail of the gripper case base, moving it back and forth until the friction feels right.
8. Repeat for the second finger.
9. Run one of the rack-and-finger assemblies into the rail of the gripper case cap the same way, until the friction feels right.
10. Insert servo 2 (the gripper servo) into the gripper case base.
11. Push the servo wires into the dedicated channel in the case.
12. Place the 3D-printed gear over the servo's output gear.
13. Slide a rack with its finger into the gripper case base rail, if it is not there already, and position it so that the outer face of the finger is flush with the side of the gripper case base.
14. Trim the servo horn to match the hole in the 3D-printed gear, insert it into the gear and fasten it with the screw supplied with the servo. Try to keep the gear from turning while you do this.
15. Slide the second rack with its finger into the gripper case cap rail, and position it so that the outer face of the finger is flush with the side of the gripper case cap.
16. Put the gripper case cap in place and secure it with two M3x16 flat head screws.

    Assembled gripper

17. Insert servo 1 (the shoulder servo) into the top part of the gripper shoulder case.
18. Insert the bottom part of the gripper shoulder case into the body front.
19. Pass the servo 2 wires through the body front.
20. Pass the top part of the gripper shoulder case through the body front.
21. Place the gripper case into the shoulder mounts.
22. Lock the gripper in position with the servo 1 horn. Trim the horn if it does not fit the niche — horns on some servos are slightly larger.
23. Fasten the horn with the screw supplied with the servo.
24. Secure the gripper shoulder with two M3x5 screws with pad.

    Gripper mounted on the body front

### Step 10. Finishing the body

1. Attach the assembled body front to the body base.
2. Connect the light, both servos and the camera sensor board.
3. Secure the body front with an M3x5 screw with pad.
4. If you are using an external antenna, install the SMA connector into the back antenna mount and insert the mount into the back add-on slot. Otherwise, fit the back add-on slot plug.
5. Connect the antenna cable to the IPEX connector on the XIAO ESP32-S3 Sense — either the pigtail of the SMA connector, or the antenna supplied with the board if you are not using an external one.
6. Insert the back door into the body back.
7. Slide the body back into position.
8. Screw the external antenna onto the SMA connector, if you are using one.

The rover is now fully assembled.

Fully assembled rover

Remote
------

### Step 1. Remote body and power circuit

1. Heat-set six M3 insert nuts into the remote body top part.
2. Solder pin headers to the XIAO ESP32-S3.
3. Solder the power circuit following the remote connection scheme.

   Recommended: do not solder the wires from the charger and the power switch directly to the battery pads of the ESP32. Use a connector instead (JST SM 2-pin or similar), so that the board can be removed later.

   Recommended: use a small piece of prototype board to join the wires at the power switch.

4. Insert the battery holder into its niche and secure it with an M3x5 flat head screw.
5. Recommended: cut two short pieces of transparent filament and insert them into the round holes next to the two USB-C openings. They act as light pipes, carrying the light of the LEDs on the modules to the outside of the remote body.
6. Insert the charger into its niche. It should be a firm fit, no extra fixing is needed.
7. Insert the power switch into its niche and fix it with hot glue.

   Remote body top part with the power circuit, charger, switch and battery holder installed

### Step 2. Controls and electronics

1. Pull the button caps off the joystick shield and refit them onto the remote button connectors.
2. Place the small buttons into their niches in the body top part.
3. Double-check that the joystick shield is set to 3.3 V mode.
4. Put the joystick shield in place and secure it with three M3x5 screws with pad.
5. Connect the ESP32 to the joystick shield using wires with female Dupont connectors, following the remote connection scheme.

    Joystick shield installed in the remote body top part

6. If you are using an external antenna, mount the SMA connector into the hole in the remote body bottom part. Otherwise, stick the antenna supplied with the XIAO ESP32-S3 onto the internal antenna pad and insert the pad into its place.
7. Connect the antenna to the IPEX connector on the ESP32.

   **Warning:** the antenna has to be in place before the board is powered in the next step.

8. If you used a connector on the ESP32 battery pads, connect the ESP32 to the power circuit.
9. Insert the ESP32 into its place. It should be a firm fit, no extra fixing is needed.
10. Bend the X and Y axis pin headers on the joystick shield to 45°, so that the body bottom part can seat fully.

    Remote electronics installed, with the SMA connector mounted in the body bottom part

11. Fit the remote body bottom part, starting from the antenna side.
12. Secure the body bottom part with two M3x5 screws.

    Assembled remote

### Step 3. Phone holder

1. Slide the phone holder cap into the base. Do it slowly — if the fit feels too tight, sand the back side of the cap with a file or sandpaper to reduce the tension.
2. Fit two rubber bands to hold the cap down against the base.
3. Insert all three rubber inserts into their niches — two in the base, one in the cap.
4. Slide the assembled holder into the slots on the remote body. Do it gently: it can be tight the first time, and sliding it in and out a couple of times loosens it up.
5. Screw the external antenna onto the SMA connector, if you are using one.

The remote is now fully assembled.

Remote with the phone holder attached

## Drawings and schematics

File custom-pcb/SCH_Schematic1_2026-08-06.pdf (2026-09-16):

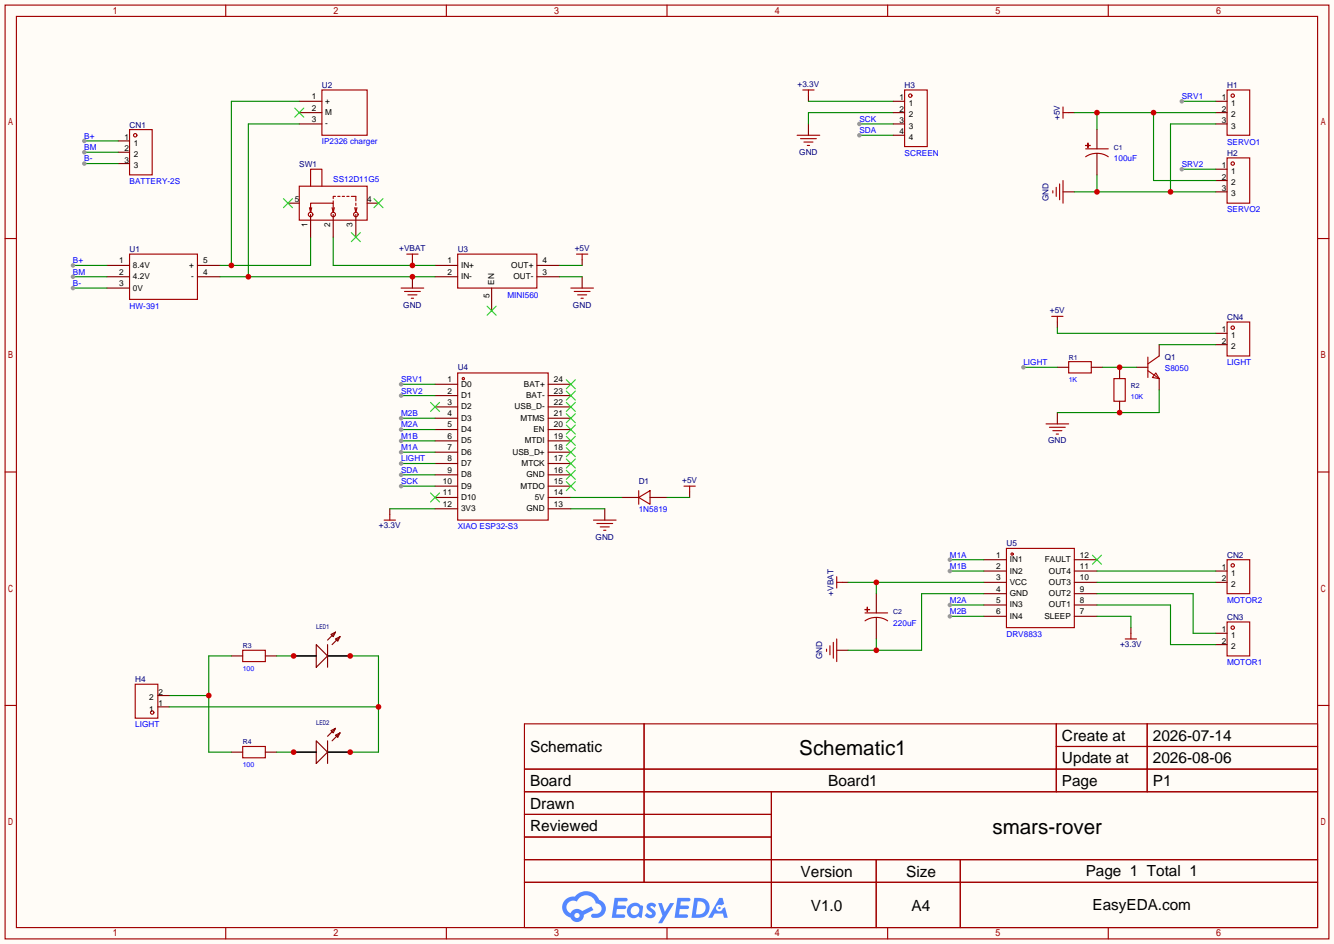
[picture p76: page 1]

Schematic | Schematic1 | Create at | 2026-07-14

Update at | 2026-08-06

Board | Board1 | Page | P1
Drawn | | smars-rover
Reviewed

Version | Size | Page 1 Total 1
V1.0 | A4 | EasyEDA.com

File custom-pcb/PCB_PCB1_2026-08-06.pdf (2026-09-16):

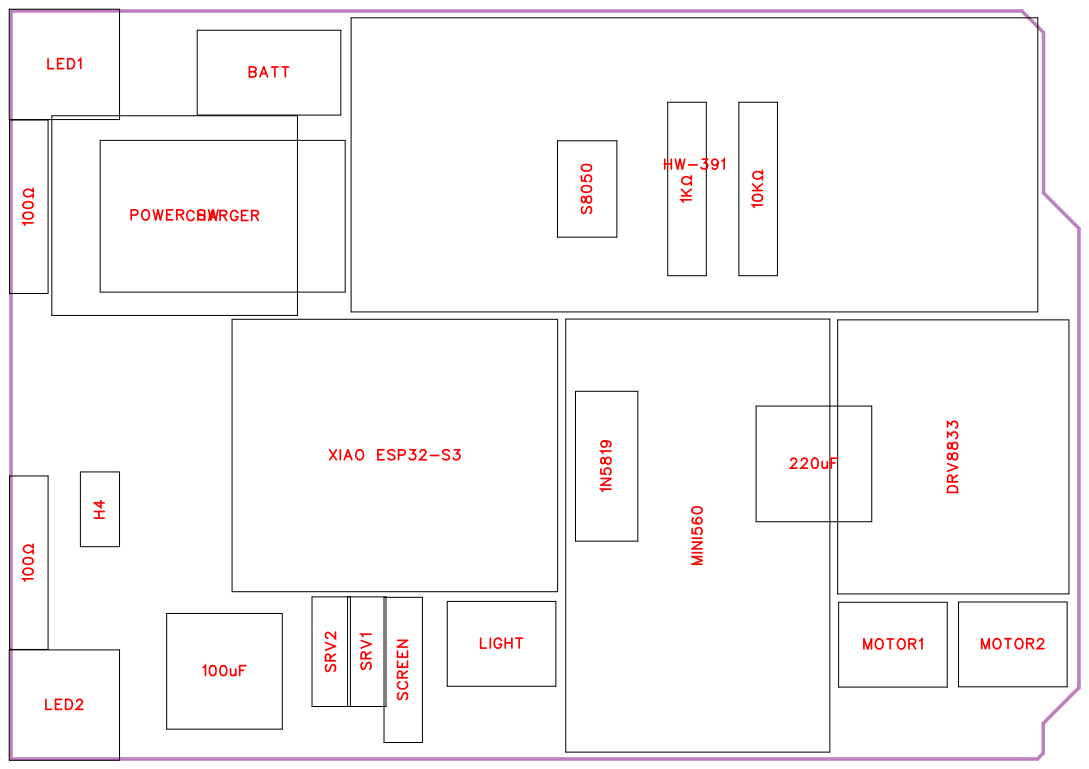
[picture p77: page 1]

No. | Quantity | Comment | Designator | Footprint | Value | Manufacturer Part | Manufacturer | Supplier Part | Supplier
1 | 1 | 1K | 1K | RES-TH_BD 2.5-L6.5-P10. 50-D0.6 | 1K | MBB02070C 2400FCT00 | VISHAY(威世 ) | | LCSC
2 | 1 | 1N5819 | 1N5819 | DO-41_BD2. 4-L4.7-P8.70 -D0.8-FD | | 1N5819 | Taiwan Semi conductor( 台 ) 湾半导体 | C3758736 | LCSC
3 | 1 | 10K | 10K | RES-TH_BD 2.5-L6.5-P10. 50-D0.6 | 10K | MBB02070C 2400FCT00 | VISHAY(威世 ) | | LCSC
4 | 1 | 100uF | 100uF | CAP-TH_BD 8.0-P3.50-D1 .0-FD | 100uF | EG22GM100 F12OTMO | Yunxing(云星 ) | | LCSC
5 | 2 | 100 | 100 ,100 | RES-TH_BD 2.5-L6.5-P10. 50-D0.6 | 100 | MBB02070C 2400FCT00 | VISHAY(威世 ) | | LCSC
6 | 1 | 220uF | 220uF | CAP-TH_BD 8.0-P3.50-D1 .0-FD | 220uF | EG22GM100 F12OTMO | Yunxing(云星 ) | | LCSC
7 | 1 | BATTERY-2 S | BATT | CONN-TH_3 P-P2.50_HC TL_XH-3A-L | | BATTERY-2 S | | C990001837 9 | LCSC
8 | 1 | IP2326 charger | CHARGER | IP2326 charger
9 | 1 | DRV8833 | DRV8833 | DRV8833
10 | 1 | LIGHT | H4 | HDR-TH_2P-P2.54-V-M-4 | | LIGHT | HDGC(华德 ) 共创 | C19190968 | LCSC
11 | 1 | HW-391 | HW-391 | HW-391
12 | 2 | F5White Piranha | LED1,LED2 | LED-TH_F5 | | F5White Piranha | ReliaPro | C10504 | LCSC
13 | 1 | LIGHT | LIGHT | CONN-TH_2 P-P2.50_XY-XH2.54-2A11 -YT | | HC-XH2.54-2 A-M | HC(虹成电子 ) | C53454745 | LCSC
14 | 1 | MINI560 | MINI560 | MINI560
15 | 1 | MOTOR1 | MOTOR1 | CONN-TH_2 P-P2.50_XY-XH2.54-2A11 -YT | | HC-XH2.54-2 A-M | HC(虹成电子 ) | C53454745 | LCSC
16 | 1 | MOTOR2 | MOTOR2 | CONN-TH_2 P-P2.50_XY-XH2.54-2A11 -YT | | HC-XH2.54-2 A-M | HC(虹成电子 ) | C53454745 | LCSC
17 | 1 | SS12D11G5 | POWER SW | SW-TH_SS1 2D11G5 | | SS12D11G5 | HanElectricit y(瀚源 ) | C48601058 | LCSC
18 | 1 | S8050SDB | S8050 | TO-92-3_L4. 8-W3.7-P2.5 4-L | | S8050SDB | FeiHong( 飞 ) 虹 | C438624 | LCSC
19 | 1 | SCREEN | SCREEN | HDR-TH_4P-P2.54-V-M_1 | | SCREEN | HDGC(华德 ) 共创 | C19190970 | LCSC

20 | 1 | SERVO1 | SRV1 | HDR-TH_3P-P2.54-V-M-1 | SERVO1 | HDGC(华德 共创 ) | C19190969 | LCSC
21 | 1 | SERVO2 | SRV2 | HDR-TH_3P-P2.54-V-M-1 | SERVO2 | HDGC(华德 ) 共创 | C19190969 | LCSC
22 | 1 | XIAO ESP32-S3 | XIAO ESP32-S3 | XIAO ESP32-S3

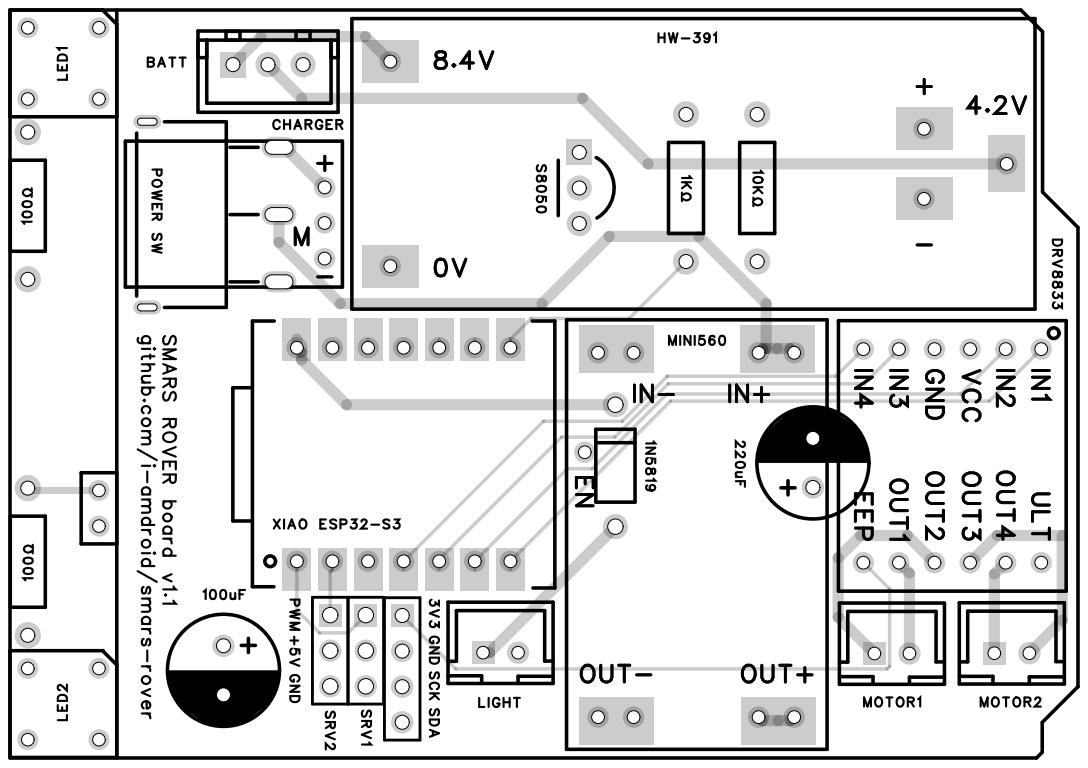
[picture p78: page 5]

github.com/i-amdroid/smars-rover

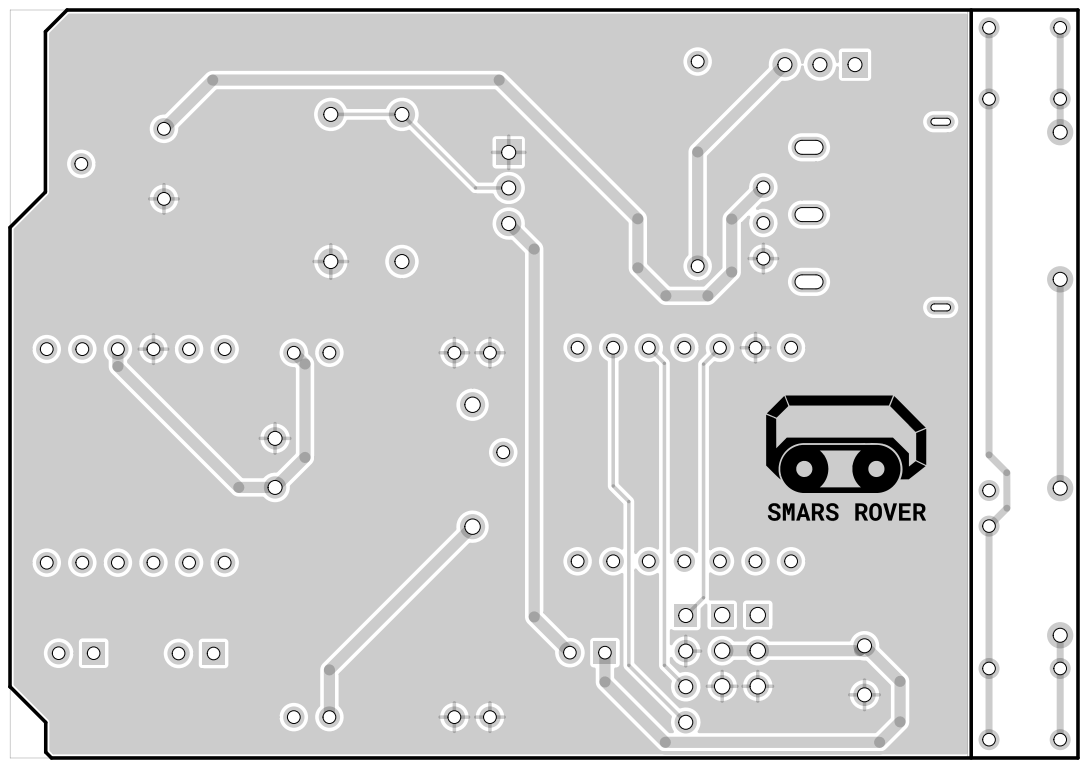
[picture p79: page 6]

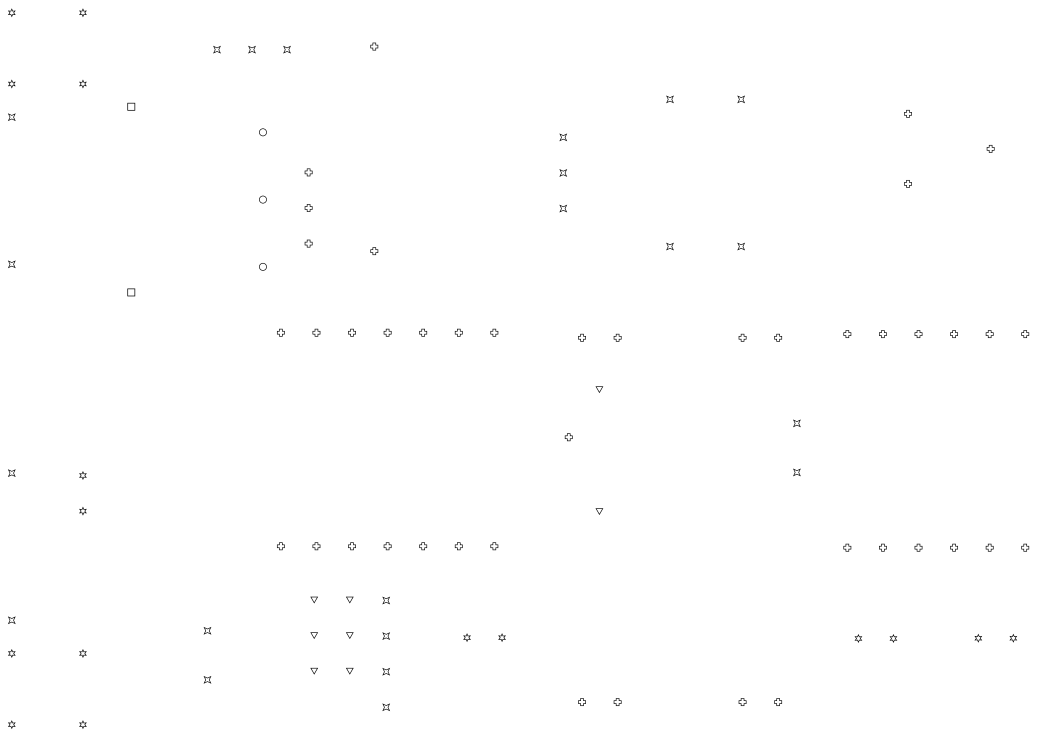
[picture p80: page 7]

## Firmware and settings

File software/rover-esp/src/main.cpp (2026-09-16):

// Rover node — drive + manipulator + ESP-NOW camera streamer.
//
//   controller --ESP-NOW joystick--> rover (this)
//   rover --ESP-NOW MJPEG video--> controller
//
// Combines the camera/ESP-NOW streamer (rover-esp) with the drive + servo
// control logic, a DRV8833 motor driver (no library — just
// PWM) and two servos.

#include <Arduino.h>
#include <WiFi.h>
#include <esp_now.h>
#include <ESPNowCam.h>
#include <drivers/CamXiao.h>
#include <ESP32Servo.h>

// Controller MAC (peer) — video is sent here. Set to your controller's MAC.
static uint8_t controllerMac[6] = {0x98, 0x3D, 0xAE, 0x61, 0x72, 0x3C};

// ===== Pins (Xiao ESP32-S3, see wiring scheme) =====
#define SERVO1_PIN 1    // D0 — shoulder
#define SERVO2_PIN 2    // D1 — gripper
#define DRV_IN1    43   // D6 \ motor 1
#define DRV_IN2    6    // D5 /
#define DRV_IN3    5    // D4 \ motor 2
#define DRV_IN4    4    // D3 /
#define LED_PIN    44   // D7 — white LEDs via S8050

// LEDC: motors on channels 4-7 (timers 2-3); ESP32Servo gets timers 0-1.
#define M1A_CH 4
#define M1B_CH 5
#define M2A_CH 6
#define M2B_CH 7
#define MOTOR_PWM_FREQ 20000
#define MOTOR_PWM_RES  8     // 0-255

// ===== Motor wiring (tune per build — nothing else needs changing) =====
// Each track is driven by one DRV8833 channel pair. Pick which pair goes to
// which track and set `reversed` if that motor spins the wrong way, to match
// your assembly. This build (bench-confirmed): connectors swapped, left reversed.
struct MotorConfig {
  int chA;         // LEDC channel -> DRV input A
  int chB;         // LEDC channel -> DRV input B
  bool reversed;   // true = swap A/B so "forward" really is forward
};
static MotorConfig leftMotor  = { M2A_CH, M2B_CH, true  };  // left  track on M2
static MotorConfig rightMotor = { M1A_CH, M1B_CH, false };  // right track on M1

// ===== Movement tuning =====
// Duty is 0-255 (8-bit LEDC). MIN raised so the N20s actually break away from
// standstill (below this they buzz but don't turn).
static const int MIN_SPEED = 70;
static const int MAX_SPEED = 200;
static const int DEADZONE = 10;
static const float MOTOR_CORRECTION = 1.0f;  // 1.0 = no trim; <1 trims right, >1 trims left
// Turn sharpness on the move: how much the inner track slows at full steer.
// 0.0 = no slowdown (goes straight); 1.0 = inner drops to a crawl. 0.6 was the
// value road-tested on the real robot.
static const float STEER_GAIN = 0.6f;
// Pivoting in place has its own duty range. It needs far more break-away
// torque than driving does — both tracks scrub sideways against the ground —
// so MIN_SPEED is nowhere near enough to start a turn. Floor it well above
// that, then cap at half of what's left up to MAX_SPEED so the pivot, once it
// does move, stays slower than a full-throttle spin.
static const int PIVOT_MIN_SPEED = 150;
static const int PIVOT_MAX_SPEED = PIVOT_MIN_SPEED + (MAX_SPEED - PIVOT_MIN_SPEED) / 2;

// ===== Servos =====
static Servo servo1, servo2;
// Shoulder 0-155 (rests at 15), gripper 0-180 (rests centred at 90).
// Tune freely; swap min/max to flip direction.
static const int S1_MIN = 20, S1_MAX = 155, S1_INIT = 35;
static const int S2_MIN = 2, S2_MAX = 178, S2_INIT = 90;
static const int SERVO_STEP_MS = 15;  // MG90S ~ this per degree
// MG90S pulse range, calibrated. Stock 500-2500 drives 0 deg past the low stop,
// where the servo jams and can stick; 600-2400 keeps both ends inside travel
// (best practice: fit min/max to the actual servo). Tune if yours differs.
static const int SERVO_MIN_US = 520, SERVO_MAX_US = 2480;
// Motion is velocity-based: while a button is held the servo steps toward its
// limit; released -> dir 0 -> it holds where it is (see servo_task).
static volatile int s1_dir = 0, s2_dir = 0;  // -1 / 0 / +1

// ===== State driven by the controller =====
static volatile bool camera_on = false;  // default OFF
static volatile uint32_t lastRecvMs = 0;

// ===== Camera / video =====
CamXiao Camera;
ESPNowCam radio;
static bool cam_inited = false;
// Image orientation (per-build): flip if the camera is mounted rotated/mirrored.
static const bool CAM_HMIRROR = true;  // false = un-mirror (correct left/right)
static const bool CAM_VFLIP   = false;  // true = flip vertically if mounted upside down
static const uint32_t FRAME_INTERVAL_MS = 60;  // ~camera ceiling; non-blocking pace
static uint32_t lastFrameMs = 0;

// Control packet — must match the controller's struct byte for byte.
typedef struct {
  int16_t x;
  int16_t y;
  uint8_t btn_up;       // A
  uint8_t btn_down;     // C
  uint8_t btn_left;     // D
  uint8_t btn_right;    // B
  uint8_t btn_e;
  uint8_t btn_f;
  uint8_t btn_joystick;
  uint8_t camera_on;    // robot streams video while set (controller-owned)
} JoystickData;

// ===== DRV8833 =====
// Speed = PWM duty on one input; direction = which input gets it; both 0 = coast.
static void driveMotor(const MotorConfig &m, int speed, int dir) {
  if (speed < 0) speed = 0;
  if (speed > 255) speed = 255;
  if (m.reversed) dir = -dir;
  if (dir > 0) {
    ledcWrite(m.chA, speed);
    ledcWrite(m.chB, 0);
  } else if (dir < 0) {
    ledcWrite(m.chA, 0);
    ledcWrite(m.chB, speed);
  } else {
    ledcWrite(m.chA, 0);
    ledcWrite(m.chB, 0);  // coast
  }
}

static void stopMotors(void) {
  driveMotor(leftMotor, 0, 0);
  driveMotor(rightMotor, 0, 0);
}

// Tank mixing. Two regimes:
//   * Moving (y != 0): smooth arc. Outer track keeps its throttle speed, the
//     inner track only *slows* (down to a crawl) — it never reverses, so the
//     turn stays gentle.
//   * In place (y == 0): pivot — the tracks counter-rotate.
static void calculateTankMovement(int16_t x, int16_t y, int &lSpeed, int &rSpeed, int &lDir, int &rDir) {
  if (abs(x) < DEADZONE) x = 0;
  if (abs(y) < DEADZONE) y = 0;

  if (x == 0 && y == 0) {
    lSpeed = rSpeed = 0;
    lDir = rDir = 0;
    return;
  }

  if (y == 0) {
    // Pivot in place: tracks spin opposite ways.
    int turn = map(abs(x), DEADZONE, 1000, PIVOT_MIN_SPEED, PIVOT_MAX_SPEED);
    lDir = (x > 0) ? 1 : -1;
    rDir = (x > 0) ? -1 : 1;
    lSpeed = rSpeed = turn;
  } else {
    // Arc: both tracks same direction; inner one slowed, never reversed.
    lDir = rDir = (y > 0) ? 1 : -1;
    int base = map(abs(y), DEADZONE, 1000, MIN_SPEED, MAX_SPEED);  // outer/throttle speed
    float steer = fabsf(x / 1000.0f);          // 0..1
    int inner = (int)(base * (1.0f - steer * STEER_GAIN));
    if (inner < MIN_SPEED) inner = MIN_SPEED;  // keep it crawling, don't stall/buzz
    if (x > 0) {          // turning right -> right track is inner
      lSpeed = base;  rSpeed = inner;
    } else if (x < 0) {   // turning left  -> left track is inner
      lSpeed = inner; rSpeed = base;
    } else {
      lSpeed = rSpeed = base;
    }
  }

  if (MOTOR_CORRECTION < 1.0f) rSpeed *= MOTOR_CORRECTION;
  else if (MOTOR_CORRECTION > 1.0f) lSpeed /= MOTOR_CORRECTION;

  lSpeed = constrain(lSpeed, 0, MAX_SPEED);
  rSpeed = constrain(rSpeed, 0, MAX_SPEED);
}

// ===== Joystick RX (raw esp_now; Arduino 2.x callback signature) =====
static void onJoystickRecv(const uint8_t *mac, const uint8_t *data, int len) {
  if (len != sizeof(JoystickData)) return;
  const JoystickData *j = (const JoystickData *)data;
  lastRecvMs = millis();

  // Drive. Wiring quirks (swapped connectors, reversed left motor) live in the
  // MotorConfig up top, so here we just hand each track its speed + direction.
  int lS, rS, lD, rD;
  calculateTankMovement(j->x, j->y, lS, rS, lD, rD);
  driveMotor(leftMotor,  lS, lD);
  driveMotor(rightMotor, rS, rD);

  // Servo 1 (shoulder): A up, C down. Servo 2 (gripper): B close, D open.
  // Hold to move, release to hold position (servo_task integrates the dir).
  s1_dir = j->btn_up    ? +1 : (j->btn_down ? -1 : 0);
  s2_dir = j->btn_right ? +1 : (j->btn_left ? -1 : 0);

  // Camera state comes from the controller (it gates the controller's UVC too).
  camera_on = j->camera_on;

  // LED is a rover-local concern: toggle on the F button edge, like A/B/C/D.
  static uint8_t f_prev = 0;
  static bool led_state = false;
  if (j->btn_f && !f_prev) {
    led_state = !led_state;
    digitalWrite(LED_PIN, led_state ? HIGH : LOW);
  }
  f_prev = j->btn_f;
}

// ===== Servo stepping task (smooth, independent of the camera) =====
// One degree per SERVO_STEP_MS while a button is held (~66°/s), clamped to each
// servo's limits. No button -> dir 0 -> the servo just holds its position.
static void servo_task(void *arg) {
  int cur1 = S1_INIT, cur2 = S2_INIT;
  for (;;) {
    if (s1_dir) { cur1 = constrain(cur1 + s1_dir, S1_MIN, S1_MAX); servo1.write(cur1); }
    if (s2_dir) { cur2 = constrain(cur2 + s2_dir, S2_MIN, S2_MAX); servo2.write(cur2); }
    vTaskDelay(pdMS_TO_TICKS(SERVO_STEP_MS));
  }
}

// ===== Camera =====
static bool initCamera(void) {
  Camera.config.pixel_format = PIXFORMAT_JPEG;
  Camera.config.frame_size = FRAMESIZE_QVGA;
  Camera.config.jpeg_quality = 18;
  Camera.config.fb_count = 2;
  Camera.config.fb_location = CAMERA_FB_IN_DRAM;
  if (!Camera.begin()) {
    Serial.println("Camera init failed");
    return false;
  }
  // Un-mirror the picture (sensor default is a horizontal mirror).
  sensor_t *s = esp_camera_sensor_get();
  if (s) {
    s->set_hmirror(s, CAM_HMIRROR ? 1 : 0);
    s->set_vflip(s, CAM_VFLIP ? 1 : 0);
  }
  return true;
}

static void deinitCamera(void) {
  esp_camera_deinit();
}

void setup() {
  // Pin the DRV8833 inputs LOW the instant we boot, before the slow init below
  // (delay, radio, camera). Left floating during that window the driver can spin
  // a motor for a second or two. LEDC takes these pins over further down.
  pinMode(DRV_IN1, OUTPUT); digitalWrite(DRV_IN1, LOW);
  pinMode(DRV_IN2, OUTPUT); digitalWrite(DRV_IN2, LOW);
  pinMode(DRV_IN3, OUTPUT); digitalWrite(DRV_IN3, LOW);
  pinMode(DRV_IN4, OUTPUT); digitalWrite(DRV_IN4, LOW);

  Serial.begin(115200);
  delay(500);

  setCpuFrequencyMhz(160);  // heat/power: enough for streaming, cooler

  // Motors (DRV8833) via LEDC. Zero each channel's duty before attaching its pin
  // so the hand-off from the low outputs above stays glitch-free.
  ledcSetup(M1A_CH, MOTOR_PWM_FREQ, MOTOR_PWM_RES);
  ledcSetup(M1B_CH, MOTOR_PWM_FREQ, MOTOR_PWM_RES);
  ledcSetup(M2A_CH, MOTOR_PWM_FREQ, MOTOR_PWM_RES);
  ledcSetup(M2B_CH, MOTOR_PWM_FREQ, MOTOR_PWM_RES);
  ledcWrite(M1A_CH, 0); ledcWrite(M1B_CH, 0);
  ledcWrite(M2A_CH, 0); ledcWrite(M2B_CH, 0);
  ledcAttachPin(DRV_IN1, M1A_CH);
  ledcAttachPin(DRV_IN2, M1B_CH);
  ledcAttachPin(DRV_IN3, M2A_CH);
  ledcAttachPin(DRV_IN4, M2B_CH);
  stopMotors();

  // LED.
  pinMode(LED_PIN, OUTPUT);
  digitalWrite(LED_PIN, LOW);

  // Servos — give ESP32Servo timers 0/1 (motors took 2/3 via channels 4-7).
  ESP32PWM::allocateTimer(0);
  ESP32PWM::allocateTimer(1);
  servo1.setPeriodHertz(50);
  servo2.setPeriodHertz(50);
  servo1.attach(SERVO1_PIN, SERVO_MIN_US, SERVO_MAX_US);
  servo2.attach(SERVO2_PIN, SERVO_MIN_US, SERVO_MAX_US);
  servo1.write(S1_INIT);
  servo2.write(S2_INIT);

  // ESP-NOW: ESPNowCam for video TX, raw recv cb for joystick RX.
  if (!radio.init()) {
    Serial.println("Radio init fail");
  }
  radio.setTarget(controllerMac);
  WiFi.setTxPower(WIFI_POWER_11dBm);  // heat: short link, less PA power
  esp_now_register_recv_cb(onJoystickRecv);

  xTaskCreate(servo_task, "servo", 2048, NULL, 5, NULL);

  Serial.println("Rover ready (camera off by default)");
}

void loop() {
  uint32_t now = millis();

  // Failsafe: no control packets -> stop driving.
  if (now - lastRecvMs > 500) {
    stopMotors();
    s1_dir = s2_dir = 0;  // don't let a servo run away if the link drops mid-hold
  }

  if (camera_on) {
    if (!cam_inited) {
      cam_inited = initCamera();
    }
    if (cam_inited && now - lastFrameMs >= FRAME_INTERVAL_MS) {
      if (Camera.get()) {
        radio.sendData(Camera.fb->buf, Camera.fb->len);
        Camera.free();
      }
      lastFrameMs = now;
    }
  } else if (cam_inited) {
    deinitCamera();
    cam_inited = false;
  }

  delay(1);  // yield
}

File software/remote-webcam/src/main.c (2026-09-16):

// Controller node — joystick transmitter + ESP-NOW video receiver + USB UVC.
//
//   controller (this) --ESP-NOW joystick--> robot
//   robot --ESP-NOW MJPEG video--> controller --USB UVC--> Android
//
// Combines the remote-simple joystick controller with the remote-webcam video
// path. Pure ESP-IDF (the USB UVC stack needs IDF 5.x and ESPNowCam doesn't
// build there), so the joystick is read and sent with the native esp_adc /
// esp_now APIs instead of Arduino + ESPNowW.

#include <string.h>
#include <stdlib.h>
#include "freertos/FreeRTOS.h"
#include "freertos/task.h"
#include "nvs_flash.h"
#include "nvs.h"
#include "esp_event.h"
#include "esp_netif.h"
#include "esp_wifi.h"
#include "esp_now.h"
#include "esp_timer.h"
#include "esp_log.h"
#include "esp_heap_caps.h"
#include "driver/gpio.h"
#include "esp_adc/adc_oneshot.h"
#include "pb_decode.h"
#include "frame.pb.h"
#include "usb_device_uvc.h"

static const char *TAG = "controller";

// Rover MAC (peer) — joystick frames are sent here. Set to your rover's MAC.
static uint8_t robot_mac[6] = {0x98, 0x3D, 0xAE, 0x60, 0x84, 0xC0};

// ===== Joystick / button pins (Xiao ESP32-S3) =====
#define JOYSTICK_X_CH    ADC_CHANNEL_0   // GPIO1
#define JOYSTICK_Y_CH    ADC_CHANNEL_1   // GPIO2
#define BTN_UP_PIN       3   // A
#define BTN_DOWN_PIN     5   // C
#define BTN_LEFT_PIN     6   // D
#define BTN_RIGHT_PIN    4   // B
#define BTN_E_PIN        9
#define BTN_F_PIN        8
#define BTN_JOYSTICK_PIN 7

// Button that toggles the robot camera on/off (change freely).
#define CAMERA_TOGGLE_PIN BTN_E_PIN

#define BTN_MASK ((1ULL << BTN_UP_PIN) | (1ULL << BTN_DOWN_PIN) | (1ULL << BTN_LEFT_PIN) | \
                  (1ULL << BTN_RIGHT_PIN) | (1ULL << BTN_E_PIN) | (1ULL << BTN_F_PIN) |    \
                  (1ULL << BTN_JOYSTICK_PIN))

// Control packet sent to the robot (raw struct, same layout both ends).
typedef struct {
  int16_t x;            // -1000..1000
  int16_t y;            // -1000..1000
  uint8_t btn_up;
  uint8_t btn_down;
  uint8_t btn_left;
  uint8_t btn_right;
  uint8_t btn_e;
  uint8_t btn_f;
  uint8_t btn_joystick;
  uint8_t camera_on;    // 1 = robot should stream video, 0 = stop
} JoystickData;

static volatile bool camera_on = false;  // default OFF (controller owns this — it
                                         // also gates the local UVC stream)

// ===== Joystick conditioning (ported from remote-simple) =====
static const int ADC_SAMPLES = 64;     // oversampling per axis
static const int OUTPUT_DEADZONE = 80; // in -1000..1000 units

// Calibration source:
//   0 = compiled-in reference + boot auto-adapt (default). Rescales the built-in
//       reference to the current supply, nothing touches NVS. A manual calibrate
//       is session-only (lost on reboot).
//   1 = persist/restore via NVS (old behaviour). Stores an absolute profile that
//       does NOT compensate for supply voltage — recalibrate per power source.
#define USE_NVS_CALIBRATION 0

typedef struct {
  int mn;
  int center;
  int mx;
} AxisCal;
// Working calibration used by map_axis().
static AxisCal calX = {0, 1886, 4095};
static AxisCal calY = {0, 1921, 4095};
// Compiled-in reference, captured once at a nominal ~3.3 V supply.
// Every boot starts from here. adapt_calibration() rescales it by
// k = center_now / center_ref to match the current supply (a ratiometric
// pot scales every reading by one k). A manual calibrate_joystick()
// overrides the working values directly (no k) for the current session only.
static const AxisCal calX_ref = {0, 1886, 4095};
static const AxisCal calY_ref = {0, 1921, 4095};

static adc_oneshot_unit_handle_t adc1;

static int64_t now_ms(void) { return esp_timer_get_time() / 1000; }

static int read_axis(adc_channel_t ch) {
  long sum = 0;
  int raw = 0;
  for (int i = 0; i < ADC_SAMPLES; i++) {
    adc_oneshot_read(adc1, ch, &raw);
    sum += raw;
  }
  return (int)(sum / ADC_SAMPLES);
}

static int map_axis(int raw, const AxisCal *c) {
  long out;
  if (raw >= c->center) {
    int span = c->mx - c->center;
    out = (span > 0) ? (long)(raw - c->center) * 1000 / span : 0;
  } else {
    int span = c->center - c->mn;
    out = (span > 0) ? (long)(raw - c->center) * 1000 / span : 0;
  }
  if (out > 1000) out = 1000;
  if (out < -1000) out = -1000;
  return (int)out;
}

// Restore an absolute profile from NVS (USE_NVS_CALIBRATION==1). These values are
// raw ADC counts tied to the supply they were captured at — no k rescaling — so
// recalibrate whenever the power source changes.
static void load_calibration(void) {
  nvs_handle_t h;
  if (nvs_open("joycal2", NVS_READONLY, &h) != ESP_OK) {
    ESP_LOGI(TAG, "No saved calibration; using defaults");
    return;
  }
  int32_t v;
  if (nvs_get_i32(h, "xc", &v) == ESP_OK) {
    calX.center = v;
    if (nvs_get_i32(h, "xmn", &v) == ESP_OK) calX.mn = v;
    if (nvs_get_i32(h, "xmx", &v) == ESP_OK) calX.mx = v;
    if (nvs_get_i32(h, "yc", &v) == ESP_OK) calY.center = v;
    if (nvs_get_i32(h, "ymn", &v) == ESP_OK) calY.mn = v;
    if (nvs_get_i32(h, "ymx", &v) == ESP_OK) calY.mx = v;
    ESP_LOGI(TAG, "Loaded calibration from NVS");
  }
  nvs_close(h);
}

static void save_calibration(void) {
  nvs_handle_t h;
  if (nvs_open("joycal2", NVS_READWRITE, &h) != ESP_OK) return;
  nvs_set_i32(h, "xmn", calX.mn);
  nvs_set_i32(h, "xc", calX.center);
  nvs_set_i32(h, "xmx", calX.mx);
  nvs_set_i32(h, "ymn", calY.mn);
  nvs_set_i32(h, "yc", calY.center);
  nvs_set_i32(h, "ymx", calY.mx);
  nvs_commit(h);
  nvs_close(h);
  ESP_LOGI(TAG, "Calibration saved to NVS");
}

// Two-phase calibration: hold centered, then sweep extremes.
static void calibrate_joystick(void) {
  ESP_LOGI(TAG, "Calibration: keep joystick CENTERED...");
  vTaskDelay(pdMS_TO_TICKS(800));

  long sx = 0, sy = 0;
  int n = 0;
  int64_t t0 = now_ms();
  while (now_ms() - t0 < 5000) {
    sx += read_axis(JOYSTICK_X_CH);
    sy += read_axis(JOYSTICK_Y_CH);
    n++;
    vTaskDelay(pdMS_TO_TICKS(10));
  }
  calX.center = sx / n;
  calY.center = sy / n;

  ESP_LOGI(TAG, "Now SWEEP to all extremes for 5s...");
  calX.mn = calY.mn = 4095;
  calX.mx = calY.mx = 0;
  t0 = now_ms();
  while (now_ms() - t0 < 5000) {
    int x = read_axis(JOYSTICK_X_CH);
    int y = read_axis(JOYSTICK_Y_CH);
    if (x < calX.mn) calX.mn = x;
    if (x > calX.mx) calX.mx = x;
    if (y < calY.mn) calY.mn = y;
    if (y > calY.mx) calY.mx = y;
    vTaskDelay(pdMS_TO_TICKS(5));
  }
  ESP_LOGI(TAG, "Calibration done: X[%d,%d,%d] Y[%d,%d,%d]",
           calX.mn, calX.center, calX.mx, calY.mn, calY.center, calY.mx);
  if (USE_NVS_CALIBRATION) save_calibration();  // else: session-only (lost on reboot)
}
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

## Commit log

2021-10-24 Updated link to LED board graphics.
2026-09-16 ESP32 powered version (#1)
    * Updated gitignore.
    * Migrated initial sketch to the new project structure.
    * Created .gitignore file.
    * Updated .gitignore.
    * Added remote simple sketch.
    * Updated .gitignore.
    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
    [antenna-pad.3mf, back-antenna-mount.3mf, back-door.3mf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]
